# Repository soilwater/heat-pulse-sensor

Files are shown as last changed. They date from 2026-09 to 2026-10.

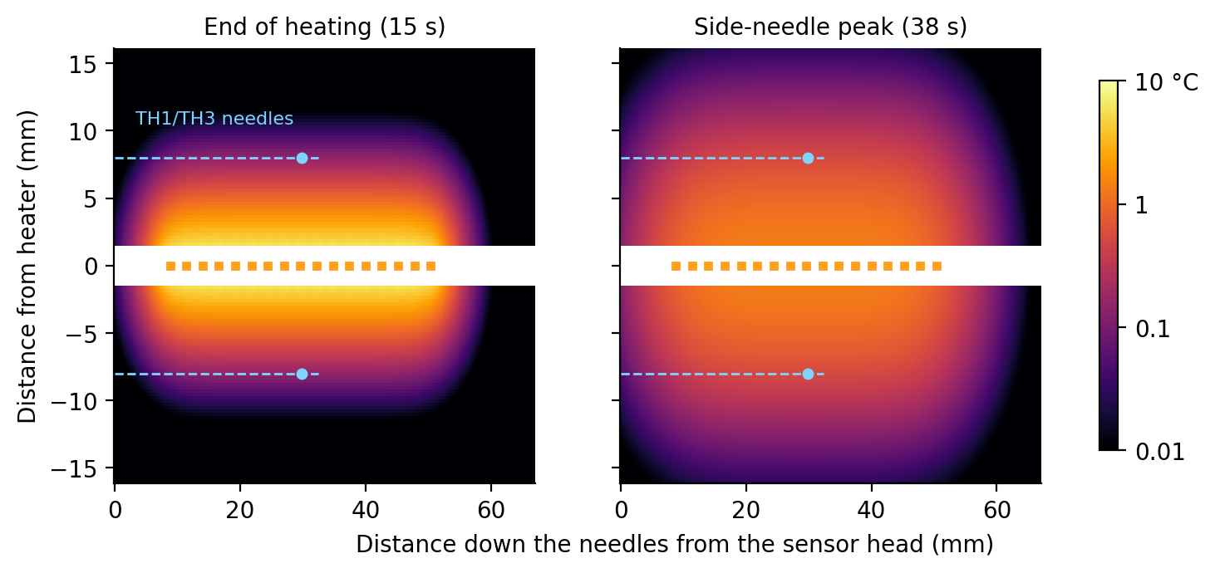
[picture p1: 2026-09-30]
docs/primer/fig/field.png

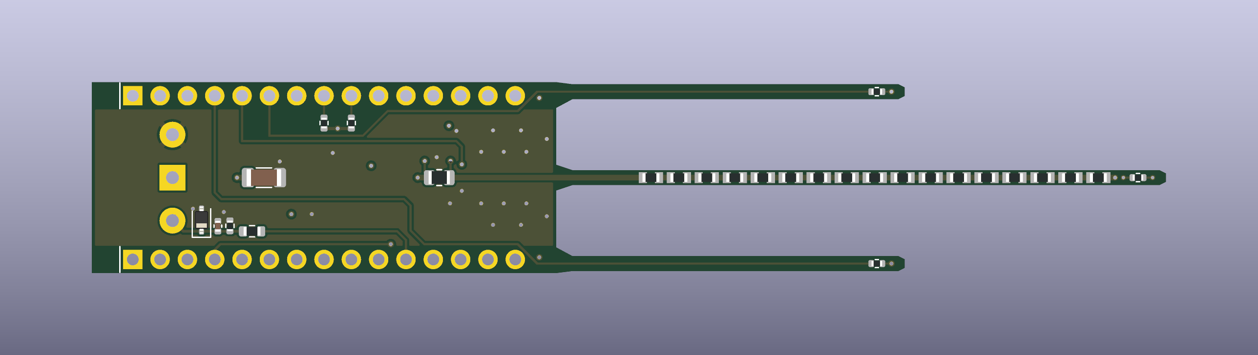
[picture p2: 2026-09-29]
hat/fab/render_top.png

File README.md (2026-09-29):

# heat-pulse

Information, datasets, and digital twins for heat-pulse sensors that measure soil thermal properties.

**Digital twin:** an interactive simulation of the HP-SDI12-NANO sensor running in real Kansas soils, published from [`docs/`](docs/). Open `docs/index.html` locally in Chrome or Edge; no installation is needed. **Guided tour** in its header steps through one measurement part by part.

## Repository layout

| Folder | Contents |
|---|---|
| [`docs/`](docs/) | The digital-twin website (static HTML, CSS and JavaScript; served as-is) |
| [`digital-twin/`](digital-twin/) | How the twin works, its data builders and tests, and the soil and heater analyses ([KANSAS_SOIL.md](digital-twin/KANSAS_SOIL.md)) |
| [`flat-nano/`](flat-nano/) | Main sensor board, HP-SDI12-NANO: KiCad sources, release checks and manufacturing files |
| [`hat/`](hat/) | Secondary design: a heat-pulse hat for the Arduino Nano R4 |
| [`reference/`](reference/) | Lab data used by the twin (Kansas Mesonet KD2 Pro workbook, logger record). Vendor manuals are kept locally, not in the repository |

## Working on the twin

```powershell
node digital-twin/sensor-model.test.js
node digital-twin/sensor-routes.test.js
node digital-twin/kansas-soil.test.js
node digital-twin/kansas-soil-build.js                          # rebuild docs/kansas-soil-data.js
& 'D:/KiCAD/bin/python.exe' 'digital-twin/export_board.py'      # rebuild docs/board-data.js from the board
```

Board release steps are in each board's README.

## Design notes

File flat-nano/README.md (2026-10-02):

# Compact flat sensor — HP-SDI12-NANO

An independent layout of the current flat heat-pulse sensor, built around the Arduino Nano R4 chip. The electronics body is **43.18 × 17.78 mm**, exactly the Arduino Nano R4 PCB outline, with every part on the top side. The WAGO connector is replaced with three plated cable solder holes. The heater is a stronger 0603 chain designed for controlled PWM heating.

## Changes after the electrical-engineering review

These changes answer an electrical-engineering review of the previous layout. The INA226 power monitor is kept; whether to keep it is still open for discussion.

- **Buck regulator instead of the linear regulator:** the HT7550-1 LDO dropped 7–9 V at the full MCU current and heated the board next to the thermistors. U3 is now a TI **LMR36503R5RPER** synchronous buck (fixed 5 V, 3–65 V input, 2.2 MHz, JLC C3190197) with a Sunlord SWPA4020S220MT 22 µH inductor (C82401), 100 nF 50 V input bypass (C307331), and a 22 µF 25 V output capacitor. Its losses are about 10 mW, on the center line.
- **Bulk input capacitor:** C3, 22 µF 25 V X5R 1206 (Samsung CL31A226KAHNNNE, JLC C12891), at the cable input.
- **Q2 removed:** D4 now powers the thermistor dividers and the ADC reference (VREF) through R11, 1.5 kΩ, which keeps the pin within the RA4M1's 4 mA output limit; the thermistors return straight to ground. Sequence unchanged: D4 HIGH, wait 10 ms, read, D4 LOW.
- **32.768 kHz crystal removed** (Y1, C5, C6): the stock Arduino core for the UNO R4 Minima / Nano R4 clocks the CPU and USB from the internal HOCO and the RTC from LOCO; it never uses the crystal.
- **USB routed as a real differential pair:** D+/D− run on the top layer only, 0.30 mm wide with a 0.20 mm gap (about 88 Ω differential on this stackup, inside USB's 90 Ω ±15 %), with no vias, over the solid inner ground plane. The SWD programming pads (J5) are removed: no external programmer is ever needed, because the chip's built-in USB boot mode (BOOT jumper on the clip) reloads the bootloader over the same clip.
- **Heater and battery current copper ≥ 0.5 mm everywhere, with no exceptions:** every trace the heater or battery current flows through, from the cable pad through the reverse-polarity diode, the shunt, the heater chain on the needle and its return, the MOSFET, and the regulator input and output, is at least 0.5 mm of 1 oz copper. The heater feed runs inside the board on the 0.5 oz In2 layer as a 1.2 mm strip, which holds more copper than a 0.5 mm outer trace, and every via on these nets has at least the barrel copper of a 0.5 mm trace. The 5 V and ground connections of the chips go through the inner planes. The three INA226 sense lines are dedicated Kelvin taps and carry no current.
- **Balanced, thermally symmetric layout:** every part that dissipates more than 2 mW (MCU, buck regulator and its inductor, input diode, 5 V OR-ing diode, shunt, heater MOSFET) sits on the board's center line. The three needles are exact mirror images, and both side-needle wires enter the body the same way. On every copper layer, the body's copper left and right of the center line must agree within 10 % (release check). This board: top 3.7 %, inner 0.9 % and 1.5 %, bottom 0.1 %.
- **Hand-planned copper, no auto-router:** every trace and via of the body is drawn deliberately by `kicad/preroute.py`. Signals run straight or at 45°. A signal changes layer only to cross the center line or another signal, and then runs at least 3 mm on the bottom layer. Every via connects copper on two layers.
- **Thermistor pin map** (same on flat-nano and the hat): A2 = TH1 right needle, A1 = TH2 heater-needle tip, A0 = TH3 left needle, A3 = TH4 board body. Left and right are as seen on the top face with the cable end up and the needles pointing down, the way the website draws the board.
- D1, D5 and D7 are Guangdong Hottech 1N5819WS 1 A 40 V Schottky diodes (SOD-323, JLC C191023, a Basic part).

**Use the complete upload set in `fab/`: `HP-SDI12-NANO_gerbers.zip`, `HP-SDI12-NANO_BOM.csv`, and `HP-SDI12-NANO_CPL.csv`. Upload all three together.**

This is the main sensor board. The `hat` folder holds the secondary Nano R4 hat design. The digital twin in `docs/` displays this board.

## Dimensions and construction

| Item | Original flat | Compact variant |
| --- | ---: | ---: |
| Electronics PCB body, excluding prongs | 60 × 18 mm | **43.18 × 17.78 mm** (Arduino Nano R4 outline) |
| Overall PCB, including prongs | 116.68 × 18 mm | **99.86 × 17.78 mm** |
| Board thickness | 0.8 mm | 0.8 mm |
| Copper layers | 2 | **4** |
| Assembly | Top side | Top side |
| Cable connection | WAGO terminal | Three plated solder holes |

The body is 16.82 mm shorter than the original flat board. All three PCB prongs are **1.4 mm wide**, providing clearance for the larger 0603 resistors within the same 12G steel needle. All prong lengths, four thermistor positions and 8 mm needle-center spacing stay unchanged. The heater uses **17 × 3.3 Ω, 1%, Vishay CRCW06033R30FKEAHP**, rated **0.33 W at 70 °C** (JLC **C313752**). Its 56.1 Ω series chain delivers about **2.34 W at 12 V** and **3.41 W at 14.4 V** under the stated cable-loss assumptions. The custom footprint follows the manufacturer's recommended reflow lands at 2.6 mm pitch. R9 is 1.5 kΩ to respect the MCU gate-drive current limit.

Use a nominal **2 W average heater-power target**, **100 Hz hardware PWM**, and **8–15 s** heating windows. At 12 V this is approximately 85% duty, with full power available when a stronger measurement is qualified. This is a firmware specification, **not implemented firmware**. See [HEATER.md](HEATER.md) for exact ratings, power calculations, synchronized current measurement, shutdown requirements and bench acceptance checks.

The 43.18 × 17.78 mm dimension describes the **bare PCB body**. The steel needles span approximately 18.77 mm across their outside surfaces, and the finished enclosure needs room for needle embedment, insulation, epoxy, and cable strain relief.

## Cable connection

J1 is a bare plated-hole feature, omitted from the factory assembly BOM and placement file. Hand-solder the three wires after assembly. There is no solder-paste aperture over these holes.

| J1 pad | Connection | Identification |
| --- | --- | --- |
| 1 | Battery +12 V | Middle pad, square, on the center line; `12V` label on underside |
| 2 | SDI-12 signal | Outer pad beside the `SDI` label on the underside |
| 3 | Ground / battery negative | Other outer pad, beside the `GND` label on the underside |

The holes have 1.2 mm nominal finished diameter, 2.4 mm copper pads, and 4 mm spacing. Use 22 AWG stranded wires with neatly tinned ends that enter freely. The nearest pad copper is 0.6 mm from the board end. Keep the cable jacket anchored in the housing or potting so cable pull does not reach the pads.

## Programming

J2 is a row of five bare holes on the long edge for an off-the-shelf 2.54 mm 5-pin pogo clip: 5V, D−, D+, GND, BOOT. Plug a "USB to 4-pin Dupont" cable onto the clip and the board is an "Arduino UNO R4 Minima" in the Arduino IDE. BOOT is used only for the very first bootloader load or for recovery: fit a jumper cap across clip pins 4–5 while plugging in. All 68 fitted components are on the top side; J1 and J2 are bare connection features.

## Files and checks

- `kicad/hp_sensor_routed.kicad_pcb`: the routed PCB.
- `kicad/hp_sensor.kicad_sch`: corresponding schematic.
- `kicad/placement.json`: component locations.
- `kicad/preroute.py`: every trace, via and pour of the body, drawn by hand plan.
- `checks/check_quality.py`: layout-quality gate for the review rules: current-path copper width, mirrored needles, left/right copper balance, heat sources on the axis, routing style (no short via-to-via jumpers, no jogs, no acute turns, no via without a purpose, no top copper under the inductor or deep under the MCU) and the USB pair.
- `kicad/export_view.py` and `kicad/plot_view.py`: layer-by-layer review drawings of the routed board.
- `preview/index.html`: dimension comparison and top/bottom assembly views.
- `fab/`: current manufacturing outputs (Gerbers, BOM, CPL, schematic PDF, renders and order settings), generated only after the release checks pass. `release.py` also writes `fab/RELEASE_MANIFEST.txt` with SHA-256 hashes of the checked board and outputs.

The release process requires zero ERC findings, zero DRC findings at all severities with zero unconnected items, schematic/PCB parity, dedicated Kelvin connections for all three current-monitor sense pins, no courtyard overlap, reserved soldering space around J1, and a pass of the layout-quality gate. A separate check keeps ordinary via holes clear of all exterior solder openings, including the cable and programming pads, to avoid solder wicking; this design does not assume filled/capped vias. This is a verified layout package; no assembled hardware has been tested.

From the project root, rebuild, check and export with:

```powershell
& 'D:/KiCAD/bin/python.exe' 'flat-nano/kicad/release.py'
```

Add `--verify-existing` to check and export the existing routed board without rebuilding it. Run with KiCad's Python environment, not a generic Python installation. This variant supports the current 12G configuration only.

## Manufacturing and assembly

Use **4-layer FR-4, 0.8 mm nominal thickness, 1 oz outer copper / 0.5 oz inner copper, green solder mask, white silkscreen, lead-free HASL finish, tented vias, and Standard PCBA on the top side only**. Select the standard **JLC04081H-7628** construction. No controlled-impedance certification is requested. The layer order is front signals, inner ground, inner +5 V (which also carries the 1.2 mm heater feed along the center line), and back signals. Both inner planes stop inside the electronics body; the needles retain their original two-sided copper construction. Unused inner via pads are removed. Keep the supplied finished-hole sizes and the needle-prong outline. Body signals are 0.2 mm wide with at least 0.127 mm clearance, and ordinary vias use 0.35 mm holes with 0.60 mm pads. Only the two heater-needle thermistor lanes use 0.09 mm traces, and the heater-needle thermistor uses two 0.30 mm-hole vias with 0.50 mm pads. The narrower paths retain the full clearance rules and fit the factory's standard multilayer capabilities.

The Gerber ZIP, BOM, and CPL must be used together from this variant's `fab/` folder. Review the supplier's component-orientation preview for this placement, in particular the polarity of D1, D5 and D7 and pin 1 of U1, U3 and U4. These local file changes do not replace files in an existing JLCPCB order; upload the three files together before production.

Any factory support tabs must be removed flush from the needle-insertion edges. Use steel needles with a measured **minimum 2.16 mm internal bore**. The heater fit calculation allows a 0.9 mm maximum PCB thickness, 1.6 mm maximum manufactured heater-prong width, 0.95 × 0.65 mm maximum resistor-plus-solder envelope and a **25 µm total radial liner including adhesive, without overlap**. Dry-fit the insulated assembly before potting; PCB thickness, routed edges, component height, and solder thickness all affect the fit. Layout checks do not replace the first assembled unit's power, programming, communication, and heating tests.

For this narrow, fork-shaped board, use **Standard PCBA with custom panel design through JLCPCB engineering and temporary supports**. The ordinary automatic Panel by JLCPCB service is not suitable for this fork-shaped outline; request the custom engineering service using the order remarks. Its minimum assembly panel is 70 × 70 mm; ordinary 5 mm rails around this 99.86 × 17.78 mm outline do not meet that width. The detailed Economic PCBA combinations do not include this four-layer, 0.8 mm construction. Request tooling holes, fiducials, and supports on the factory panel, with the sensors delivered separately and all remnants removed flush from needle-insertion edges. These supports are not part of the 43.18 × 17.78 mm finished body. Use the exact wording and settings in `fab/ORDER_SETTINGS.md`. See [assembly capabilities](https://jlcpcb.com/capabilities/pcb-assembly-capabilities) and [panel requirements](https://jlcpcb.com/capabilities/Capabilities).

The explicit stack follows [JLCPCB's published 0.8 mm JLC04081H-7628 construction](https://jlcpcb.com/impedance): 0.035 mm outer copper, 0.2104 mm 7628 prepreg, 0.0152 mm inner copper, 0.250 mm core, 0.0152 mm inner copper, 0.2104 mm 7628 prepreg, and 0.035 mm outer copper. The 0.0152 mm inner value belongs to the factory's nominal 0.5 oz option. The solder-mask model uses the published 0.01524 mm above-copper thickness on each side. Their combined model is 0.80168 mm; the specified finished thickness remains nominal 0.8 mm with the factory's published ±0.1 mm tolerance. The Gerber job records these published construction dimensions without claiming controlled impedance or a measured loss tangent.

For durable soil service, fully encapsulate the assembled electronics and cable entry using electrically insulating, low-water-absorption potting suitable for electronics. Insulate copper from the steel needles, anchor the cable mechanically, and dry-fit each assembled prong before potting. The surface finish and solder mask do not replace waterproof encapsulation.

Select **Board Cleaning: No**: the Murata NCP15 thermistors must not be cleaned after no-clean flux. Do not solvent-wash, dry-ice-clean or ultrasonically clean the assembled board. Follow the component-specific cleaning and potting guidance and the 500-character assembly remark in [ORDER_SETTINGS.md](fab/ORDER_SETTINGS.md). Evaluate the chosen potting process on a finished sensor before encapsulating the batch.

The separate solder-opening check also found ordinary via holes overlapping SMD solder openings in the original flat PCB. Those locations are corrected in this compact layout. The original board and its manufacturing files were deliberately preserved; this release does not certify their soldering geometry.

Dimension reference: [Arduino Nano R4 datasheet, mechanical drawing](https://docs.arduino.cc/resources/datasheets/ABX00142-datasheet.pdf). Manufacturing reference: [JLCPCB capabilities](https://jlcpcb.com/capabilities/Capabilities), including 0.8 mm board thickness tolerance ±0.1 mm, regular routed dimensions ±0.2 mm, and plated-hole tolerance +0.13/−0.08 mm.

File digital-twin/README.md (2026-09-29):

# Flat heat-pulse sensor dashboard

The dashboard itself lives in [`../docs/`](../docs/) and is published from there as the project website. Locally, open **`docs/index.html` in Chrome or Edge on a desktop computer**; double-clicking works without a server, installation, or internet connection. This folder holds the twin's documentation, data builders and tests. The dashboard is a single control view: the sensor drawing on the left; the temperature chart and one live **Readings** table on the right. Above them, a control row uses the same two columns: the Soil and Parts cards over the sensor, and the run controls over the chart. Soil selection and the parts list open as dialogs from those cards. The header switch changes between the dark theme (default) and the light theme; the choice is saved in this browser. It represents the current **HP-SDI12-NANO** (flat-nano) sensor with **17 series-connected 3.3 Ω resistors**, a **12 V battery**, and a **22 °C starting temperature**. It simulates a proposed measurement sequence; it does not connect to hardware or execute sensor firmware.

## Run a measurement

Three durations and one heater-duty setting are editable, and the soil is chosen with the **Soil** card above the sensor. Durations use whole seconds; duty uses whole percent:

| Setting | Range | Default |
|---|---:|---:|
| Background (sensing before heating) | 1–60 s | 10 s |
| Heating | 8–15 s | 15 s |
| Cooling (sensing after heating) | 1–600 s | 150 s |
| Heater duty | 0–100% | 85% |

## Choose a soil

Every soil is a real measurement. The **Soil** card above the sensor shows the current one (station, depth, water state, texture, λ, C, θ); it opens on a typical silty clay loam at 33 kPa, the reading closest to the Kansas 33 kPa medians. **Change** opens the **Select soil** dialog:

- Click a dot on the USDA texture triangle. There is one dot per Kansas Mesonet core; the two cores at each station depth share a position, so click again to cycle. Hover for station, depth, texture and the colored variable.
- Or narrow the list with **Texture** and pick from **Core** (grouped by station, keyboard accessible).
- **Color by** organic matter, bulk density, depth, or water content at the selected state.
- Pick a **water state** chip. Each shows that reading's water content θ. A "!" marks heat capacities flagged in the workbook's QA/QC log (all 5 and 10 kPa readings, plus individual cores); they remain selectable, and the flag text is shown.

The twin applies the choice immediately and uses that single reading's measured conductivity and heat capacity; nothing is interpolated. The dialog lists the core's texture, OM, bulk density, θ, λ and C, and plots the actual KD2 Pro reading of that sample next to the twin's prediction for the KD2 probe (30 mm, 6 mm spacing, 60 s heating), so each soil can be traced back to a real measurement. See [KANSAS_SOIL.md](KANSAS_SOIL.md) for the data, the model check against all 1,448 curves, and the expected signal range.

Press **Run measurement**, pause/resume, reset, or run again. Drag the time slider to inspect any moment. Playback speed cycles through **1×, 4×, and 10×**; this changes animation speed, not the simulated pulse duration. Changing a timing or duty value resets the measurement. Duty is the fraction of each 100 Hz PWM cycle that the heater switch is ON. At 0%, the measurement sequence still runs but the heater stays off.

Displayed time **0 starts background sensing**. The default cycle lasts **175 seconds** and contains exactly the three phases above. The underlying model's initial idle and final reporting intervals are not displayed.

The vertical sensor view uses the actual PCB outline, component positions, and copper snapshot. Scroll over the board to zoom at the pointer, or use **+ / −**; drag to pan and press **Fit** to restore the whole board. Zoom ranges from 100% to 600%. Clicking a component, a callout, or a Readings row opens its role and current values in a detail dialog; dragging does not open a dialog.

The **Parts / Top / In1 / In2 / Bot** tabs preserve zoom, pan, measurement time, and playback. Copper tabs hide component bodies and show the selected layer's actual tracks, filled copper areas, pad outlines, and drill holes. All four copper views use the same top-view coordinates; inner and bottom copper are viewed through the board, not mirrored. In1 is the ground plane. In2 is the +5 V plane and also carries the heater supply (VIN_P) as a 1.2 mm strip along the board's center line. Both inner planes stop inside the electronics body. Via annuli and pads appear only on layers where the board actually flashes copper; through-drill holes remain visible on every layer they traverse. Pad clicks and the component callouts still open details.

The drawing is a top view on a 1 mm drafting grid with a title block. Callouts give each designator and its function. The soil-temperature and circuit-activity legends float in the drawing's upper-left corner.

## Guided tour

**Guided tour** in the header walks through one measurement in 20 stops: an overview, the cable holes, surge protection and the bulk capacitor, the reverse-polarity diode, the 5 V buck regulator, the battery and USB supply diodes, the processor, the programming clip, the SDI-12 request, thermistor excitation through pin D4, how a thermistor divider measures temperature, the background reading, the heater switch, energy measurement, the heater chain, heat spreading, heater off, the side-needle peak, the board thermistor, and the result. Everything except the sensor is blurred; the camera flies to each part while its current flow is highlighted, and a card explains it at two levels: a short “In plain terms” line (the processor as the brain, a transistor as a gate, why a resistor heats up, how a thermistor senses temperature) followed by the technical account of what happens and why the part is there, with live values from the current soil. The tour also explains why the heater runs on the raw 12 V battery supply (trimmed by switching) while the processor runs on a regulated 5 V.

**Space** (or →, Enter) runs the simulation forward to the next event and stops; **←** goes back; **Esc** exits. The progress bar jumps to any stop.

The tour is two self-contained files: `tour.js`, a generic engine (spotlight, blur, card, keys, camera and time stepping) that knows nothing about heat pulses, and `tour-steps.js`, this sensor's script as plain data (parts to frame, when, plain-language line, what, why). A tour for another board needs only a new steps file and a twin exposing `seek(time)` and a camera with `focus(refs)`. The dashboard works without either file.

## Readings and the sensor estimate

The **Readings** table updates with the time slider: TH1, TH3 and TH2 temperatures and rises, the soil beside the heated section, battery draw and current, heater power and energy, and the component losses. TH4 (board) stays on the drawing but is not reported, because board heating is not modeled. Click any row for details.

**Sensor estimate** answers "what would this sensor report in this soil?". When cooling ends, the simulated TH1 record (14-bit ADC, 64 readings averaged, one sample per second) is baseline-corrected and fitted with the pulsed infinite-line-source model, as simple firmware would: from heater-on to 1.5 times the time of the measured peak (readings after that are kept but not fitted), using q′ = average heater power ÷ effective heated length (17 resistors × 2.6 mm = 44.2 mm) and the nominal 8 mm spacing. If the record ends before the peak, the estimate is flagged. The table shows the sensor's λ and C next to the soil's KD2 Pro values, with the difference. Water content is then derived from C with the de Vries relation θ = (C − ρb·0.75)/4.18 and the core's bulk density, and compared with the measured θ. The λ and C differences are the model error of the sensor and analysis, mostly from the finite heater length: about 1% or less for λ and 0.3% or less for C across Kansas soils with the default settings. The θ difference also contains the de Vries relation's own error: in the wetter states, measured C averages about 6–9% below the relation, with ±11–14% scatter.

## Parts list

The **Parts list** card opens one table of all 70 footprints (68 fitted parts plus the two hole rows), grouped by part number: designators, function, value, manufacturer, part number, LCSC number and BOM description. These are the 68 assembled components plus the J1 cable holes and the J2 programming-clip holes, which are bare hole features with no BOM rows. The BOM has no manufacturer column; manufacturers are filled in only for part-number families that identify them unambiguously, otherwise a dash. Click a designator for that part's role and live values.

J1 is drawn as three plated cable holes with incoming **12 V power, SDI-12 signal, and ground** wires from an external battery/logger. Pad 1 (+12 V) is the square middle hole on the board's center line; pad 2 (SDI-12) and pad 3 (ground) are the outer holes, 4 mm to either side. Dimension lines show **99.86 mm overall PCB length × 17.78 mm width** (43.18 mm body length, the Arduino Nano R4 outline), calculated from the exported outline and excluding the wires. All three PCB prongs are 1.4 mm wide.

Neon **yellow logic-power** and **pink signal** highlights follow the **actual exported copper tracks and vias**. Each copper tab shows activity only on its selected layer, including the **orange heater circuit**: the 0.5 mm series links between heater resistors on top, the 0.5 mm return trace (HEAT_RTN) on top and bottom, and the 1.2 mm heater-supply strip on In2. Every trace on the heater and battery-input path (cable hole, D1, R5, the heater chain and its return, Q1, and the regulator input and output) is at least 0.5 mm wide; the INA226 sense taps carry no current and are narrower, as is the 0.3 mm output-sense line to U3 pin 8 (VOUT/BIAS), which carries only U3's small bias current. In the Parts tab the orange heater path follows that copper from the middle cable hole through D1, R5 and the 17 resistors, then back along HEAT_RTN to Q1 (the shared ground-plane return is not drawn); the In2 strip is drawn there as a hatched line running under the parts. Copper pads and fills also indicate activity; shared supply and ground use yellow during sensing and orange during heating. These colors indicate circuit activity, not voltage, current density, or decoded waveforms. Supply/heater nets include sensing and protection branches, so their copper highlights pulse without claiming equal branch current or a direction everywhere. Heater traces without highlights do not necessarily have zero voltage. Component selection uses a thin unfilled rectangular border that keeps its screen width when zooming.

Before a measurement, the board uses muted copper and component colors with no automatic activity highlights. The electronics are still powered and their standby draw remains visible in the Readings table. Running or scrubbing a measurement enables highlights, including background sensing at displayed time zero. Pausing freezes them at that moment; reset clears them.

The chart and Readings table show the evolving ideal thermal response: **TH1/TH3** on the side needles and **TH2** at the heater-prong tip. Component details also show the last simulated ADC reading. The Readings table updates PWM-cycle-average battery draw, heater power, accumulated heater energy, and component/group losses. Resistor and switch dialogs also show ON current and ON power. Copper animation represents average activity; it does not flash at 100 Hz or reconstruct actual switching waveforms. **The electronics stay powered during background sensing and cooling**, even when heater power is zero.

The soil colormap uses **purple → pink → orange → yellow** and the same spatial heat equation as the temperature curves. Its fixed, logarithmically spaced **0–5 °C rise scale** keeps small side-needle responses visible without rescaling a cooling pulse; values above 5 °C saturate. The map is neutral before heating, remains warm after switch-off, and follows the same time across all copper tabs, zoom and pan. It refreshes at quarter-second simulation intervals. The physical heater-needle interior is masked rather than assigned a fictitious temperature. The map runs from the sensor head (the end of the PCB body) past the needle tips and treats everything outside the needles as uniform soil. The **References** button in the footer lists the heat-pulse theory and data sources the model uses.

**TH2 (labeled "heater tip") is 3.68 mm beyond the last heater resistor.** A separate **Soil beside heater** reading samples the ideal soil field at the middle of the heated length, 1.385 mm from the axis (the nominal 12G needle outer radius). This is a soil estimate, **not the steel, thermocouple or resistor temperature**. Click this reading or the color legend for the distinction and a comparison with the recorded experiment. The thermistor chart keeps its smaller scale so the side-needle signal remains readable.

## Heating capacity and the recorded probe

The heater chain is **17 × 3.3 Ω = 56.1 Ω** in series, using Vishay CRCW06033R30FKEAHP (LCSC C313752), 0.33 W, 1%, 0603 resistors. They are spaced 2.6 mm apart, beginning 8.8 mm from the body/prong boundary. The dashboard shows only this board and has no hardware configuration selector.

At the fixed **12 V** supply and modeled cable/circuit losses, full ON gives **204.5 mA and 2.346 W**. The default **85% duty** gives **1.994 W average and 29.91 J over 15 seconds**. Increasing duration increases energy; increasing duty increases average power. A duty of 100% delivers approximately 35.18 J in 15 seconds under these assumptions.

**The dashboard applies a fixed duty, not closed-loop power regulation.** Real firmware is intended to regulate around 2 W average at 100 Hz as battery voltage changes. For example, the model requires approximately 85.3% at 12 V but 58.6% at 14.4 V. Leaving duty at 85% on a 14.4 V supply would produce approximately 2.90 W average. That firmware has not been implemented or qualified by this dashboard.

[HEATER.md](../flat-nano/HEATER.md) records the heater part choice, electrical limits, needle fit, insulation assumptions, and bench qualification requirements. Neither the soil model nor passing PCB design rules establishes the hottest chip temperature or adequate thermal signal in a manufactured sensor.

[HEATER_CHECK.md](HEATER_CHECK.md) is the earlier analysis of `reference/probe_A25-2.dat`, the supplied construction manual, and the first 22 × 5.1 Ω heater design. Thirteen valid records show approximately 60–63 °C on the inferred heater-thermocouple channel and approximately 1.5 °C side-channel rises. The manual describes a 35–45 Ω wire heater and 14G needles. The logged heater-millivolt signal has no documented power conversion, so those records do not calibrate the current 56.1 Ω, 12G sensor. A hot needle alone does not establish the side-needle response needed for measurement.

## What the circuit model represents

- Heater current flows through **J1 pad 1 (middle hole) → D1 → VIN_P, which runs inside the board on In2 as a 1.2 mm strip → R5 → RH1–RH17 → HEAT_RTN → Q1 → ground plane → J1 pad 3**. C3 (22 µF) on VIN_P supplies the heater’s sudden current steps locally, so the long cable does not ring. Pin D9 controls Q1's gate through R9; the processor does not supply heater current. Each heater resistor releases **I_ON²R** during each ON interval. Average heat is this power multiplied by duty / 100, not the square of average current times resistance.
- **U3** is a TI LMR36503R5RPER synchronous buck regulator: fixed 5 V output, 3–65 V input, switching at up to 2.2 MHz, with L1 (22 µH), C1 (4.7 µF, 50 V input), C18 (100 nF, 50 V input bypass), C19 (100 nF bootstrap), C20 (1 µF internal supply) and C2 (22 µF output). Its loss is about 10 mW. **D7** (B5819WS Schottky) follows it onto the +5 V rail (C17, 10 µF) and keeps clip power out of the regulator; the model assumes a 0.25 V drop. The power ledger separates these losses from aggregate logic consumption. It does not invent individual processor or INA226 current consumption.
- **U4/INA226** senses R5 and HEAT_P. Its calculated power includes heater-loop copper and Q1 losses; delivered heater energy counts the 17 resistors alone. Proposed firmware must use settled ON-window single-shot shunt/bus conversions, check conversion-ready, and integrate measured ON power over actual ON time. Asynchronous PWM averages can alias and cannot simply be multiplied. The twin uses ideal ON/OFF weighted averages and does not simulate conversion timing errors.
- **R9** (1.5 kΩ, pin D9 to the Q1 gate) limits the processor's gate-charging current, and **R10** (100 kΩ) holds the gate LOW while the processor is in reset. Firmware must detach PWM and explicitly drive the heater output LOW at the deadline; stopping a timer alone is insufficient.
- Processor pin **D4** (net D4_EXC, U1 pin 45) powers VREF through **R11** (1.5 kΩ). VREF feeds the tops of the four 10 kΩ, 0.1% thermistor dividers and the ADC reference AREF (C13, 1 µF); the thermistors return straight to ground. R11 limits the pin to 5 V / 1.5 kΩ = 3.3 mA while C13 charges, within the RA4M1's 4 mA per-pin rating. With the dividers connected, VREF sits at roughly 3.5–3.7 V at 25 °C (higher when cold); readings stay ratiometric because the dividers and AREF share VREF. The dividers are unpowered between readings. The proposed sequence is pin D4 HIGH, 10 ms settling (the time constant is about 1.2 ms), 10 ms acquisition of 64 readings with `AR_EXTERNAL` and 14-bit ADC conversions, then pin D4 LOW, once every second.

Other settings are fixed in the dashboard: 5 m one-way 22 AWG cable, zero additional contact resistance at the soldered cable holes (idealized), 0.2 Ω heater-loop copper, 0.35 V D1 drop, 10 mA aggregate electronics current, 8 mm needle spacing, and uniform soil with the selected reading's λ and C. See **Model assumptions** for these limits while using the dashboard.

## Limits

The electrical model assumes constant resistance, diode drops, and electronics current. The selected Vishay CRCW06033R30FKEAHP heater is rated 0.33 W at ambient temperatures up to 70 °C, with linear derating to zero at 155 °C. Rating checks use full-ON power and resistance tolerances regardless of selected duty. Calculated power is a screening result, not qualification of the assembled needle.

Thermal curves sum finite heater point sources in homogeneous soil. They exclude steel, epoxy, PCB heat storage, contact resistance, water movement, and temperature-dependent heater resistance. **Resistor-chip temperature is not predicted. Board heating is not modeled, so TH4 is not reported.** TH1 and TH3 overlap because the modeled soil and spacing are symmetric.

ADC values include deterministic quantization and approximate settling, not validated noise, accuracy, or self-heating. The dashboard does not test SDI-12 compatibility, bootloaders, surge protection, or physical insulation. Hardware testing and calibration remain necessary.

## Source files and updates

Web app, in `docs/` (served as-is; no build step):

| File | Purpose |
|---|---|
| `index.html`, `sensor-ui.js`, `sensor.css` | Dashboard, timing and duty controls, chart, Readings table, sensor estimate, parts list, playback, and dialogs |
| `sensor-board.js`, `sensor-components.js` | Vertical PCB rendering, zoom/pan, component interactions, and explanations |
| `sensor-routes.js`, `sensor-annotations.js` | Actual copper selection, soldered cable illustration, and outline dimensions |
| `sensor-soil.js` | Select soil dialog: texture triangle, core and water-state selection, KD2 Pro curve |
| `tour.js`, `tour-steps.js`, `tour.css` | Guided tour: generic engine, this sensor's step script, and styles |
| `sensor-heatmap.js` | Fixed logarithmic soil colormap, sampled from the shared spatial temperature model |
| `sensor-model.js` | Electrical/measurement model, PWM average power ledger, ON-state values, and the sensor estimate (`soilEstimate`) |
| `engine.js` | Shared ideal-soil thermal calculations |
| `kansas-soil-data.js` | Every Kansas Mesonet core with its KD2 Pro readings, generated by `kansas-soil-build.js` from `reference/kansas_mesonet_soil_database_summary_2026.xlsx` (read by `xlsx-read.js`) |
| `board-data.js` | Exported PCB geometry, nets, BOM identities, and source hashes |

Tooling, in `digital-twin/` (not published):

| File | Purpose |
|---|---|
| `export_board.py` | Regenerates `docs/board-data.js` from the routed KiCad board and BOM, without editing KiCad sources |
| `kansas-soil-build.js`, `xlsx-read.js` | Builds `docs/kansas-soil-data.js` from the reference workbook and prints the model checks |
| `sensor-model.test.js`, `sensor-routes.test.js`, `kansas-soil.test.js`, `sensor-ui.test.cjs` | Model, routing geometry, soil-data and browser checks against the files in `docs/` |
| `KANSAS_SOIL.md`, `HEATER_CHECK.md` | Soil-data analysis and the original heater investigation |

`board-data.js` records SHA-256 hashes of `flat-nano/kicad/hp_sensor_routed.kicad_pcb` and `flat-nano/fab/HP-SDI12-NANO_BOM.csv`; the dashboard reads this snapshot rather than live KiCad data, and `sensor-routes.test.js` fails until both hashes match. After either source changes, regenerate from the repository root:

```powershell
& 'D:/KiCAD/bin/python.exe' 'digital-twin/export_board.py'
```

The compact board snapshot contains four copper layers and the saved fills, without altering the manufacturing files. J1 is three plated cable holes (no connector). The copper-loss value remains an explicit estimate, not a four-layer resistance extraction.

The exporter updates geometry, BOM metadata, and explicit heater specifications. It refuses an unexpected heater count, identity, or position. Review the model and tests separately after changes to circuit values, topology, geometry, or timing; the physics does not update automatically.

Run checks from the repository root:

```powershell
node digital-twin/sensor-model.test.js
node digital-twin/sensor-routes.test.js
node digital-twin/kansas-soil.test.js
node digital-twin/sensor-ui.test.cjs
```

`sensor-ui.test.cjs` drives the dashboard in headless Chrome: the 70 drawn parts and the current nets, copper-exact activity highlights, layer tabs, zoom and pan, playback, dialogs, the parts list, the guided-tour parts and desktop layout. It requires Playwright, which is not installed on this machine; point `PLAYWRIGHT_MODULE` at a local copy, and `CHROMIUM_EXECUTABLE` can identify an installed Chrome or Edge. These dependencies are needed only for automated tests, not for opening the dashboard.

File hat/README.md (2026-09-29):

# Compact Nano R4 heat-pulse hat

Current design: **HP-HAT**, four layers, 0.8 mm thick. The 43.18 × 17.78 mm body is exactly the Arduino Nano R4 outline and pin layout, with parts on both faces.

- [Assembly dimensions, selected headers and drawing](mechanical/ASSEMBLY.md)
- [Design, operation and manufacturing files](fab/README_HAT.md)
- [JLCPCB order settings](fab/ORDER_SETTINGS.md)
- [Release checks and file hashes](fab/RELEASE_MANIFEST.txt)

The `flat-nano` version is the reference for the needles and shared parts; its files are only read. The Nano and hat are soldered face inward with a 4.00 mm gap. The potted body target is 10.5 mm thick, which the nominal 10.49 mm stack meets only with the full 1 mm cover per face; verify the fit on the first assembly.

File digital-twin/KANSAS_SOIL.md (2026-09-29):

# Kansas Mesonet soil data in the digital twin

Source: `reference/kansas_mesonet_soil_database_summary_2026.xlsx`, a copy of the workbook in the
`kansas-soil-props` repository (SHA-256 `1c543b63…2025101`). Cite Parker, Kluitenberg, Redmond &
Patrignani (2022), *SSSAJ* 86(6):1495–1508, https://doi.org/10.1002/saj2.20465.

The workbook links 1,448 KD2 Pro SH-1 dual-needle readings to 316 of its 320 cores (40 stations, 5–50 cm,
8 water states). SH-1: 30 mm needles, 6 mm spacing, 60 readings 2 s apart, heater on for the first 60 s.
Texture coverage is silt loam, silty clay loam, silty clay, clay loam, loam and 24 sandy-loam cores:
**there are no sands**, so these data do not cover the Feb-2026 sand tests.

Rebuild and re-run the checks (≈3 s, Node only):

```powershell
node digital-twin/kansas-soil-build.js          # writes docs/kansas-soil-data.js and prints the checks
node digital-twin/kansas-soil.test.js
```

## In the dashboard

The **Select soil** dialog picks any of the 316 cores (texture triangle, texture filter or core list) and
any of its water states; the twin then runs on that single reading's measured λ and C, and the dialog shows
the reading's KD2 Pro curve beside the twin's prediction for it. The dashboard opens on the unflagged 33 kPa
reading closest to the 33 kPa medians (Hodgeman, 20 cm, silty clay loam: λ 1.28, C 2.35). After each run,
the Readings table's *Sensor estimate* shows the λ, C and θ the flat-nano sensor itself would report for that
soil (Check 2's line-source bias, computed live). See the README for how to use it.

Particle size was measured on one core of each station-depth pair (core 2) and organic matter on the
other (core 1), so both cores take texture and OM from their pair. Bulk density and all thermal readings
are each core's own.

For context, the medians per water state (printed by the build) are:

| Water state | n | λ W/(m·K) | C MJ/(m³·K) | θ m³/m³ |
|---|---:|---:|---:|---:|
| Saturated | 316 | 1.37 | 2.73 | 0.44 |
| Field capacity (33 kPa) | 312 | 1.29 | 2.33 | 0.34 |
| 70 kPa | 242 | 1.25 | 2.16 | 0.32 |
| Air-dry (2 days) | 208 | 1.05 | 1.75 | 0.17 |
| Oven-dry (40 °C) | 220 | 0.43 | 1.31 | 0.02 |

5 and 10 kPa are omitted here because the workbook's `qaqc_log` flags all of their heat capacities
(~30% low); individually flagged heat capacities are also excluded. In the panel, flagged readings stay
selectable but are marked "!" with the flag text.

## Check 1 — does the twin's heat model reproduce real curves?

Each KD2 curve was predicted from its own reported λ, C and heater power (W/m), using the same
`engine.js` functions the dashboard uses:

| Model | Peak predicted / measured (p5 · median · p95) | RMSE, median |
|---|---|---|
| Finite 30 mm heater (the twin's point-source sum) | 0.99 · **1.04** · 1.13 | 0.05 °C |
| Infinite line source | 1.01 · 1.06 · 1.15 | 0.09 °C |

The finite-length model the twin uses halves the error of the textbook line source. The remaining ~4%
overestimate is consistent with what the model leaves out (needle heat capacity, contact resistance).
When the finite model is fitted freely to the raw curves, C agrees with the KD2 value within ~2% (median),
but λ comes out ~9% higher. The instrument's λ is probably biased low, so treat KD2 λ as ±10%.

## Check 2 — what will the flat-nano sensor see in Kansas soils?

The default pulse (1.99 W average, 15 s, 8 mm spacing), run through all 1,448 measured (λ, C) pairs:

| Quantity (p5 · median · p95) | Value |
|---|---|
| Side-needle peak rise | 0.41 · **0.58** · 1.05 °C |
| Saturated soils only | 0.39 · 0.45 · 0.56 °C |
| Oven-dry soils only | 0.71 · 0.94 · 1.37 °C |
| Time of peak after heater on | 28 · 39 · 64 s |
| Soil beside heated section (needle surface) | 5.4 · 7.1 · 17.6 °C rise |
| Line-source analysis error, λ / C (finite heater only, no noise; effective length 17 × 2.6 mm, fit to 1.5 × the peak time) | λ +0.1 · +0.2 · +0.3% / C +0.0 · +0.1 · +0.1% |

Implications:

- **Wet soils give the smallest signal.** About 0.4 °C is the design case, not 0.6 °C (λ 1.5, C 2.0, the model's generic default soil).
  At 0.0063 °C per 14-bit code that is roughly 60–70 codes before noise, so noise and drift, not
  quantization, will limit C resolution. This makes the case for averaging or a longer/stronger pulse in wet soil.
- **Dry soil runs hot.** Oven-dry cores push the needle-surface soil to about +16 °C (up to +22 °C) with
  the same energy. That is a steep gradient that can drive water away from the heater in moist soil,
  and it is the hotter environment for the heater resistors.
- **Record length.** The latest peak in the Kansas data (an oven-dry core, 15 s pulse) comes 98 s after the heater
  switches on; the median is 39 s. The default 150 s cooling phase (165 s of record after heater-on) covers 1.5 × the
  peak time for every state, with margin to locate the peak. A 90 s cooling phase would end only 7 s after that latest peak.
- **Analysis error is small.** With the effective heated length (17 × 2.6 mm = 44.2 mm) and a fit from heater-on to
  1.5 × the peak time, the finite-heater error is 0.3% or less for λ and 0.1% or less for C (5th–95th percentile)
  across all Kansas states. Fitting further into the tail, where the ideal line and the finite heater agree least,
  pulls λ up.
  Needle spacing, needle heat capacity, contact and noise will dominate real-sensor errors.

## Check 3 — the engine's texture-based soil-property model (`engine.soilProps`, not used by the dashboard)

Against 1,398 measurements with texture, bulk density and water content: λ RMSE 0.20 W/(m·K) (refitting its
constants to Kansas data improved this only to ~0.18 with leave-one-station-out validation), C biased +0.12 MJ/(m³·K) overall. It
underestimates oven-dry λ by 0.18. It is not refitted because the dashboard uses measured
values directly; refit it before using it to predict properties from texture and water content.

## Limits

- KD2 Pro properties come from a 60 s heat pulse on a 30 mm, 6 mm-spaced probe. λ and C are soil
  properties and transfer to the flat-nano geometry; the KD2 *curves* do not reproduce a 15 s, 8 mm measurement.
- The readings are on small intact cores in the lab. Field contact resistance, layering and water
  redistribution around the heater are not represented.

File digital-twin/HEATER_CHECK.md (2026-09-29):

# Heater performance check — original investigation (22 × 5.1 Ω heater)

**The current flat-nano board supersedes the manufacturing decision in this original investigation.** It uses **17 × 3.3 Ω, 0.33 W Vishay heaters**, totaling 56.1 Ω. The original experimental data remain useful, but the heater calculations below describe the first 22 × 5.1 Ω PCB. See [the flat-nano heater decision and qualification](../flat-nano/HEATER.md) and [the current upload set](../flat-nano/fab/ORDER_SETTINGS.md).

The dashboard includes a duty-cycle control. At 12 V, 85% duty and 15 s, it predicts **1.994 W average**, **29.91 J** and approximately **0.607 °C side-needle rise** under the stated ideal-soil assumptions. At 100% duty the same pulse gives **2.346 W**, **35.18 J** and **0.714 °C**; at 14.4 V / 100% it gives **3.412 W**, **51.18 J** and **1.039 °C**. These remain model predictions, not measured PCB performance. On the current board TH2 is 3.68 mm beyond the last heater center; it does not measure the hottest resistor.

The field-control specification targets approximately **2 W average using measured power**, so it would reduce duty as the battery charges. The dashboard's direct duty control instead lets you inspect a fixed 12 V example. Neither the dashboard nor this specification constitutes implemented sensor firmware.

---

Initial review, 23 September 2026. This note addresses the concern that the hardware must be able to **“deliver a punch if necessary.”** The recorded measurements confirm a hot heater needle in the older wire-heater probe. The first 22 × 5.1 Ω PCB had less heater power, and the digital twin cannot certify its assembled thermal performance. At the time of this initial check, no manufacturing files or component selections had been changed.

## What the recorded experiment shows

Source: [probe_A25-2.dat](../reference/probe_A25-2.dat). Its TOA5 header identifies a CR1000 and the program `One Thermo-TDR Probe Calibration Andreas All TCs.CR1`; that program source is absent. The table has 4,200 readings: fourteen 300-second records at one-second intervals, starting every two hours. `Htr_mV` is nonzero at counters 8–22 inclusive: fifteen heated samples per record.

For each record, baseline is the arithmetic mean of counters 0–7; peak is the largest subsequent channel value; rise is peak minus baseline. The first record contains impossible T2 values and T3 startup faults, so its T2/T3 results are excluded. No filtering was applied to the thirteen subsequent records. T2's units field is blank; its stable baseline, pulse response and comparison with the construction manual strongly indicate the heater thermocouple, but the missing logger program prevents definitive channel-map verification.

| Channel, thirteen valid records | Median baseline | Median peak | Median rise | Rise range | Median peak after switch-on |
| --- | ---: | ---: | ---: | ---: | ---: |
| T1 | 17.958 °C | 19.436 °C | 1.477 °C | 1.465–1.512 °C | 85 s |
| T2, inferred heater thermocouple | 17.969 °C | 60.211 °C | 42.241 °C | 42.215–44.743 °C | 14 s |
| T3 | 17.969 °C | 19.486 °C | 1.517 °C | 1.440–1.542 °C | 83 s |

T2 peaks at **60.163–63.208 °C**, always on the last heated sample. These data support the reported 50–60 °C heater temperatures. The median standard deviation of the eight baseline samples is approximately 0.0026 °C for T1/T3 and 0.0020 °C for T2; those short-record statistics characterize this older setup, not the PCB's thermistors or ADC.

| Record start | T1 rise | T2 baseline → peak | T3 rise |
| --- | ---: | ---: | ---: |
| 2025-03-18 10:00 | 1.408 °C | invalid startup | invalid startup |
| 2025-03-18 12:00 | 1.479 °C | 18.085 → 60.480 °C | 1.514 °C |
| 2025-03-18 14:00 | 1.481 °C | 17.995 → 60.290 °C | 1.515 °C |
| 2025-03-18 16:00 | 1.476 °C | 18.005 → 60.220 °C | 1.520 °C |
| 2025-03-18 18:00 | 1.477 °C | 17.946 → 60.211 °C | 1.518 °C |
| 2025-03-18 20:00 | 1.478 °C | 17.965 → 60.203 °C | 1.521 °C |
| 2025-03-18 22:00 | 1.512 °C | 17.990 → 60.226 °C | 1.542 °C |
| 2025-03-19 00:00 | 1.476 °C | 17.944 → 60.180 °C | 1.517 °C |
| 2025-03-19 02:00 | 1.466 °C | 17.922 → 60.163 °C | 1.516 °C |
| 2025-03-19 04:00 | 1.476 °C | 17.961 → 60.203 °C | 1.513 °C |
| 2025-03-19 06:00 | 1.477 °C | 17.981 → 60.235 °C | 1.518 °C |
| 2025-03-19 08:00 | 1.465 °C | 17.969 → 60.202 °C | 1.504 °C |
| 2025-03-19 10:00 | 1.484 °C | 17.925 → 60.163 °C | 1.527 °C |
| 2025-03-19 12:00 | 1.495 °C | 18.465 → 63.208 °C | 1.440 °C |

## Why the older probe is a different heater

The supplied [Thermo-TDR Construction Manual](<../reference/Thermo-TDR Construction Manual.pdf>) (kept locally; not in the repository) provides these primary construction details:

- **Page 4:** the center needle contains both the heater and a thermocouple. All three thermocouple junctions lie at the same axial position, within the heated section; adjacent needles are 8 mm apart.
- **Page 7:** 38 AWG heater wire is folded three times over a 42 mm guide. A handwritten note specifies approximately 35–40 Ω.
- **Page 24:** the printed heater acceptance range is **35–45 Ω**.
- **Page 25:** the heater wire is Nichrome 80, 40.63 Ω/ft; the needles are **14 gauge stainless steel**, filled with thermally conductive Omegabond 101 epoxy.

With an ideal **12 V actually across 35–45 Ω**, this construction would dissipate **3.20–4.11 W**. That is a conditional circuit calculation, not measured power from the log. `Htr_mV` averages approximately 296–302 mV during heating, but the shunt value and conversion to current are undocumented. The log therefore does not establish exact amperes, watts or pulse energy. The previous 37 Ω / 0.30 A estimate is consistent with the construction range but is not a measured calibration recovered from this file.

The first 22 × 5.1 Ω PCB had a **112.2 Ω** heater (22 × 5.1 Ω), a 43 mm heated length, **12 gauge needles**, epoxy and an FR-4 prong. Different steel, epoxy and PCB heat storage prevent direct transfer of the older probe's calibration.

## What the first 22 × 5.1 Ω PCB and original model provided

The following calculations use the twin's circuit-loss assumptions: 5 m one-way 22 AWG cable, 0.35 V input-diode drop, 0.1 Ω shunt, 0.032 Ω MOSFET, 0.2 Ω heater-loop copper and 10 mA electronics load. Side-temperature predictions assume homogeneous soil with conductivity **1.5 W/(m·K)**, heat capacity **2 MJ/(m³·K)** and **8 mm spacing**.

| Battery / pulse | Heater power | Heater energy | Energy per heated length | Predicted side-needle rise |
| --- | ---: | ---: | ---: | ---: |
| 12 V / 8 s | 1.190 W | 9.52 J | 221 J/m | 0.197 °C |
| 12 V / 12 s | 1.190 W | 14.28 J | 332 J/m | 0.293 °C |
| 12 V / 15 s | 1.190 W | 17.85 J | 415 J/m | 0.364 °C |
| 14.4 V / 15 s | 1.731 W | 25.97 J | 604 J/m | 0.529 °C |

Changing 8 s to 15 s increases energy by **87.5%** without increasing instantaneous resistor power. A battery at 14.4 V provides about **45% more power** than at 12 V under these assumptions. Neither change makes the 22 × 5.1 Ω heater equivalent to the older 35–45 Ω wire heater. Treat 14.4 V as a normal charging condition, not a requirement to boost the battery. Do not overdrive that chain's 0.1 W resistors to chase a needle temperature.

The twin's **TH2 is at the heater-prong tip**, at axial position 54.08 mm; the last center of the 22 × 5.1 Ω chain was at 50.8 mm (on the current board, RH17's center is at 50.40 mm, 3.68 mm short of TH2). The older thermocouple lies inside the heated section. Even within the same ideal model, a 12 V / 15 s pulse from the 22 × 5.1 Ω chain gives about **0.64 °C rise at TH2's location** versus **4.85 °C at the heated midpoint**, using the model's 0.85 mm effective radius. Neither number predicts the temperature of a resistor chip or the actual steel needle. Steel conduction, epoxy/contact resistance, FR-4 heat storage and water movement are absent from the model.

## Acceptance decision and a stronger candidate

Use **15 s as the initial intended pulse** when testing the 22 × 5.1 Ω hardware; [HEATER.md](../flat-nano/HEATER.md) gives the qualification plan for the current board. For this project, adopt a provisional engineering acceptance target of **at least 0.5 °C rise on each side needle and at least ten times its measured baseline RMS noise**, in representative wet and dry media at the lowest intended battery voltage. This is a chosen practical margin, not a universal heat-pulse physics threshold. Also verify repeatability, recorded heater energy and recovery of known reference-medium properties. A hot center needle alone does not establish adequate signal at the sensing needles.

The 22 × 5.1 Ω chain's 12 V / 15 s model result (0.364 °C) is **below that chosen 0.5 °C target**. Physical tests may differ, but the evidence could not certify that hardware against this target or promise the older probe's response.

The initial 0402 candidate, subsequently superseded by the stocked 0603 Vishay selection, was **22 × Panasonic ERJPA2J2R7X, 2.7 Ω, ±5%, 0402**, giving 59.4 Ω total. Its ERJPA2 series specifies **0.20 W at 70 °C ambient**, with a separate 0.25 W terminal-temperature rating. Use the conservative 0.20 W screening figure while evaluating actual terminal temperatures and derating; these ratings are not interchangeable. See the [Panasonic ERJP/ERJPA datasheet, ratings and derating on pages 2–3](https://industrial.panasonic.com/cdbs/www-data/pdf/RDO0000/AOA0000C331.pdf).

With the same circuit-loss assumptions, this candidate gives approximately **2.22 W at 12 V** and **3.23 W at 14.4 V**, or **33.3–48.4 J for 15 s**. The one-high/21-low ±5% resistance corner gives approximately **0.116 W / 0.169 W** in the hottest resistor at those two supplies. These are screening calculations. Exact sourcing and factory assembly, component/package compatibility, switch/protection margins, thermal behavior and pulse safeguards still require qualification. This was a candidate calculation only. The current board uses the 17-part Vishay design identified at the top of this note.

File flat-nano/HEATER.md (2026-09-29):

# Flat-nano heater decision and qualification

Engineering review: 23 September 2026. This heater has more power than the original flat board's, while retaining the Nano-size electronics body and the existing needle lengths and sensing positions. The selected parts and circuit calculations support the design; they do not constitute physical validation of a manufactured, insulated and potted sensor.

## Selected components

| Function | Exact part | JLCPCB part | Quantity per board | Public stock checked |
| --- | --- | --- | ---: | ---: |
| Heater | Vishay **CRCW06033R30FKEAHP**, 3.3 Ω, ±1%, 0603, **0.33 W at 70 °C ambient** | [C313752](https://jlcpcb.com/partdetail/VishayIntertech-CRCW06033R30FKEAHP/C313752) | 17 | 1,534 |
| R9 gate resistor | UNI-ROYAL **0402WGF1501TCE**, 1.5 kΩ, ±1%, 0402, 62.5 mW | [C25867](https://jlcpcb.com/partdetail/26610-0402WGF1501TCE/C25867) | 1 | 2,202,352 |

Stock was returned by JLCPCB's public component search at **2026-09-23 22:03 UTC**, not reserved. Heater prices were $0.1097 each for 1–49 pieces, $0.089 for 50–149, and $0.0788 for 150–499; the 17 fitted heaters therefore cost approximately $1.87 per board at the smallest tier before assembly, attrition and other charges. Gate resistors were $0.0029 each at 1–999. JLCPCB reported heater minimum placement quantity 5 and attrition quantity 2; its final quotation determines the charged quantity.

The heater chain is **17 × 3.3 Ω = 56.1 Ω nominal**, with centers spaced 2.6 mm. Nominal cold resistance is 55.539–56.661 Ω before wiring, copper and switch resistance. This is a different calibration from the previous 22 × 5.1 Ω chain; update firmware configuration, heater validation limits and thermal geometry together. An aggregate resistance measurement cannot identify every individual resistor defect.

The [Vishay primary datasheet, revision 17 March 2026](https://www.vishay.com/doc?20043=), specifies the 0.33 W ambient rating, temperature derating, lead-free-compatible pure-tin terminations and reflow assembly. Its separate terminal-temperature rating is not used to inflate the conservative rating here. Page 9 gives a maximum body envelope of 1.70 × 0.95 × 0.55 mm. Recommended reflow lands are 0.75 mm long × 1.00 mm wide each, 0.75 mm apart internally, for 2.25 mm total length. At 2.6 mm pitch, adjacent pads have a nominal 0.35 mm gap before solder-mask expansion. Film temperature must remain within the manufacturer's limit; the assembled potting process also requires qualification.

## Available power and the PWM operating requirement

The table assumes 5 m one-way 22 AWG cable (0.53 Ω loop), a 0.35 V input diode drop, 0.1 Ω shunt, 0.032 Ω MOSFET, 0.2 Ω heater-loop copper, and 10 mA electronics load. These are design estimates, not measurements.

| Battery voltage | Full-ON current | Full-ON heater power | Full-ON energy, 8 / 15 s | Duty for 2.0 W average |
| --- | ---: | ---: | ---: | ---: |
| 11.5 V | 0.196 A | 2.147 W | 17.18 / 32.21 J | 93.1% |
| 12.0 V | 0.204 A | 2.344 W | 18.76 / 35.17 J | 85.3% |
| 14.4 V | 0.247 A | 3.410 W | 27.28 / 51.16 J | 58.6% |

The intended default is **2.0 W average heater power, 100 Hz PWM, 8–15 seconds**. This gives **16–30 J** independent of battery voltage while sufficient electrical headroom remains. Closed-loop control must use measured power; the percentages above are explanatory starting estimates. Longer or thinner cables, a low battery, or higher actual circuit losses can prevent 2 W. Saturate at 100% duty, report achieved power/energy, and flag an unmet target rather than extending the authorized pulse silently.

**These are firmware requirements, not a claim that PWM regulation has been implemented or tested.** Every configuration must retain a hard maximum heating duration of 15 s and an explicit OFF state on reset, faults and measurement completion. Detach/disable the PWM output and then drive its GPIO LOW: stopping a timer alone must not leave the output HIGH. Full-ON operation is available for qualified experiments; the normal target remains 2 W. Do not raise the battery voltage above the intended charging range to obtain more power.

PWM reduces average power but does not reduce the instantaneous power during ON intervals. For one resistor at +1% and the other sixteen at −1%, the hottest resistor dissipates approximately **0.142 W at 12 V** and **0.206 W at 14.4 V**, using the losses above. Ignoring all circuit losses gives conservative supply-voltage bounds of **0.155 W** and **0.224 W** respectively. The latter is approximately 68% of the 0.33 W rating at or below 70 °C. Apply temperature derating; at 100 °C the conservative ambient rating is approximately 0.214 W, below that zero-loss bound. Resistance temperature coefficients and measurement errors require additional margin.

Use **90 °C as a provisional maximum measured hottest-resistor temperature during qualification**, leaving margin below the conservative ambient derating intersection. This is a chosen operating limit, not a temperature that current hardware can guarantee or directly monitor. **TH2 is near the prong tip and is not a measurement of the hottest resistor.** Assess the hottest region with an independent temperature measurement during bench qualification.

## Gate drive and measured energy

R9 changes from 1 kΩ to **1.5 kΩ ±1%** (R12 was removed together with Q2). The [Renesas RA4M1 datasheet, table 2.6](https://www.renesas.com/en/document/dst/ra4m1-group-datasheet), limits the relevant GPIO source-current group to 4 mA. At 5.5 V, 1.485 kΩ limits the initial ideal gate-charge current to approximately 3.70 mA. The gate pulldown R10 remains essential. A 100 Hz carrier allows slow, low-loss switching without using a high switching frequency merely for appearance.

The [TI INA226 datasheet](https://www.ti.com/lit/ds/symlink/ina226.pdf) describes sequential shunt and bus conversions. Unsynchronized PWM sampling can alias; multiplying independently averaged current and voltage does not generally give the correct heater energy. The implementation requirement is a settled ON window with single-shot shunt-plus-bus conversion, **588 µs configured per conversion, averaging 1**, allowing the specified conversion maximum of approximately 646 µs per channel and polling conversion-ready. Check that both conversions finish inside the same ON interval. Average valid cycles in software and integrate measured ON power over actual ON time. At very small requested duty, the measurement method must explicitly preserve a sufficiently long ON window or use another validated acquisition scheme.

INA226 bus voltage is sensed at HEAT_P. Its voltage-times-current result includes downstream copper and MOSFET dissipation as well as the heater resistors. Subtract characterized downstream losses when reporting resistor-only energy, or clearly identify the result as delivered heater-loop energy. Validate the complete method against an independent current/voltage measurement; the twin's ideal duty-weighted result does not validate conversion timing.

## Needle fit and insulation

All three PCB prongs are narrowed to **1.40 mm nominal**; their lengths, spacing and thermistor positions stay unchanged. The mechanical acceptance envelope is **actual width no greater than 1.60 mm**, **PCB thickness no greater than 0.90 mm**, and a resistor envelope **0.95 mm wide × 0.65 mm above the PCB**. The last figure includes the manufacturer's 0.55 mm maximum body height plus a **0.10 mm engineering allowance for solder standoff**, which must be verified on assembled boards. The Murata thermistors also have a 0.55 mm maximum height, so the same solder-height allowance is used for their fit checks. The heater needle's two bottom thermistor lanes run at ±0.455 mm beside the 0.5 mm heater return and use 0.09 mm traces, 0.16 mm from the return trace and 0.135 mm from the return via's pad (the release DRC minimum is 0.127 mm). The tip thermistor's two vias use 0.50 mm pads with 0.30 mm holes; the heater-return via is 0.55/0.35 mm, so its barrel holds at least the copper of a 0.5 mm trace. Body signal traces are 0.2 mm, and other vias are 0.60/0.35 mm. The [factory's standard multilayer capabilities](https://jlcpcb.com/capabilities/Capabilities) accommodate these sizes without an ENIG or filled-via requirement.

Require an **actual minimum unobstructed bore of 2.16 mm** over the insertion region; a nominal gauge or catalog ID alone does not establish that minimum. Checking all four PCB corners and all four component corners together, the maximum bare cross-section above has a minimum enclosing diameter of approximately **2.051 mm**. A uniform **25 µm radial** internal dielectric liner reduces diameter by 50 µm, leaving a **2.110 mm usable bore** and approximately **0.059 mm diametral clearance**. The 0.65 mm component height excludes this liner; the liner is counted once through the bore reduction. The heater and TH2 share one tube-axis position along the rigid prong. The side needles have about 0.118 mm diametral clearance with their narrower thermistor envelope. A conservative ±0.10 mm lateral heater-placement allowance reduces heater-needle diametral clearance to approximately 0.016 mm. This supports the design envelope but does not guarantee a slip fit through an irregular real needle. A thicker adhesive layer, seam overlap, solder protrusion, burr or local bore restriction can invalidate it.

If a liner is used, **25 µm means its total installed thickness including adhesive**, with no overlap in the insertion section. Ordinary tape specified as 25 µm film plus adhesive does not meet that envelope automatically. Dry-fit and inspect the actual assembled, insulated prong in the actual needle before potting; never force it or scrape its insulation. Reject or rework combinations that bind, and check electrical isolation from steel before and after potting. A measured larger bore or smaller actual prong provides useful margin. The dimension calculation does not certify coating uniformity, long-term insulation or moisture resistance.

## Physical qualification before field deployment

Test complete assemblies in representative **wet and dry intended media**, at the lowest intended battery voltage and at 14.4 V. Measure current, ON timing, integrated energy, actual hottest-resistor temperature, side-needle response and recovery. Repeat pulses to assess drift and repeatability, and check resistance and steel isolation after curing and environmental exposure.

For this project, use a provisional acceptance target of **at least 0.5 °C rise on each side sensing needle and at least ten times its measured baseline RMS noise**. These are chosen engineering margins, not a universal standard. Also confirm that measurements recover known reference-medium properties with the required accuracy. A hot heater needle by itself is insufficient evidence. Layout/ERC/DRC and the digital twin can support these checks; none can promise a successful first physical sensor or replace the assembled thermal and insulation tests.

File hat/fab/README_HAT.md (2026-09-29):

# HP-HAT — compact heat-pulse sensor for Arduino Nano R4

The hat applies the same review rules as flat-nano, at the exact Arduino Nano R4 footprint:

- **Nano outline and pins.** The body is exactly the Nano R4 PCB outline, **43.18 × 17.78 mm**, with the Nano's two pin rows at their exact positions. To fit, parts sit on **both faces**. The top face, toward the Nano, carries low parts inside the 4 mm gap. The bottom face, outward, carries the power stage, INA226 and thermistor dividers, which the potting covers.
- **Power copper.** Every trace carrying heater, battery or Nano-supply current is at least 0.5 mm on the outer layers, with no narrower neck. The heater supply (VIN_P) and the Nano supply (NANO_VIN) run inside the board as 1.2 mm strips on the 0.5 oz In2 layer, which is more copper than 0.5 mm of 1 oz outer copper. Every via on those nets has a barrel at least equal to that trace. The cable ground hole and both Nano ground pins connect to the pours through 0.5 mm spokes.
- **Heat on the axis.** Every part dissipating more than 2 mW sits on the center line: D1, R18, R5 and Q1.
- **Balanced left and right.** The three needles are exact mirror images, and both side-needle wires enter the body the same way. On every copper layer, the body's copper left and right of the center line must agree within 10 % (release check). This board: top 7.2 %, inner 0.5 % and 3.2 %, bottom 6.7 %. To help the top side balance, the right-needle (TH1) and tip (TH2) thermistor wires run north of the center line and the left-needle (TH3) wire south of it.
- **Hand-planned copper.** Every trace and via of the body is placed by `kicad/preroute.py`, and `kicad/gen_pcb.py` draws the needle copper, identical to flat-nano; no auto-router. Signals run straight or at 45°, and a via appears only where a signal changes layer.

Carried over from the previous hat circuit: bulk input capacitor C3 (22 µF 25 V 1206), no Q2 thermistor switch (D4 drives the dividers and AREF through R11, now 1.5 kΩ so the pin stays within the RA4M1's 4 mA output limit), and the SMF15CA input TVS.

Needles, needle copper and the heater and needle thermistors are identical to flat-nano; both bodies are the 43.18 × 17.78 mm Nano outline. The complete bare PCB outline is **99.86 × 17.78 mm**. It uses **four copper layers, 0.8 mm nominal thickness and lead-free HASL**. The flat-nano files are only read, never changed.

Use a **headerless Arduino Nano R4, ABX00142**, with its components facing the hat's top face across a **4.00 mm gap**. Two **Samtec HTSW-115-07-T-S** strips are soldered to both boards, making a permanent compact stack. The field cable is soldered into J1's three holes from the hat's outer face. Ordinary loose pins held by epoxy are not reliable electrical contacts.

The parts on the hat's outer face add up to 1.55 mm there. That puts the nominal potted stack at **10.49 mm with 1 mm of epoxy over each face**, so the 10.5 mm body target is met only nominally. Before committing a mold, check the first assembly and choose between a thinner cover over the hat's outer face and a thicker mold. See the [assembly guide and drawing](../mechanical/ASSEMBLY.md) for dimensions, part sources, wire routing and tolerances.

## Manufacturing files

Use these three files together:

| File | JLCPCB upload |
| --- | --- |
| `HP-HAT_gerbers.zip` | PCB Gerbers (includes top and bottom paste) |
| `HP-HAT_BOM.csv` | Assembly BOM |
| `HP-HAT_CPL.csv` | Assembly placement, top and bottom |

[ORDER_SETTINGS.md](ORDER_SETTINGS.md) contains the factory selections and a remark below 500 characters. The PCB has **49 factory-fitted components**:

- **28 on the top face:** the 17 heater resistors, the three needle thermistors, shunt R5, bulk capacitor C3, the SDI-12 protection (R3, R4, C4, D4) and the I2C pull-ups R6 and R7.
- **21 on the bottom face:** D1, D2, C1, C17, R18, Q1, R9, R10, U4, C12, R11, C13, TH4 and the divider bank R21–R24 and C21–C24.

J1, J3 and J4 are deliberately excluded from the assembly BOM/CPL; fit the wires, headers and Nano after delivery. Purchase the Nano and two HTSW strips separately; they are not supplied by this JLCPCB package.

The editable board is `../kicad/hp_hat_routed.kicad_pcb`. Its matching schematic is `../kicad/hp_hat.kicad_sch`. Changes belong in the generators, `placement.json` and `preroute.py`, so that rebuilding preserves the design. Run `D:\KiCAD\bin\python.exe hat/kicad/release.py` from the project folder to regenerate, check and export. `--verify-existing` checks and exports the existing routed board without rebuilding it.

## Operation and shared components

Use the intended clean **12 V battery/logger supply, normally 11.5–14.4 V**, with **8–15 s heater pulses**. RH1–RH17 are the same heater as flat-nano: Vishay **CRCW06033R30FKEAHP**, 17 × 3.3 ohm 0603 in series, nominally 56.1 ohm, 0.33 W each at 70 °C. Full-on at 12 V is roughly 2.3–2.5 W; the intended default is 2 W average via 100 Hz PWM with a hard 15 s limit. See `flat-nano/HEATER.md` for the power, derating and needle-fit calculations. Use INA226 measurements to calculate delivered energy. Resistor tolerance, temperature, potting and pulse repetition still matter; these calculations are not a completed thermal qualification.

D2 retains the hat's SMF15CA, the intentional exception to the flat-nano shared BOM, for the Nano supply branch. The Nano's regulator supplies the 5 V circuits. R18 is a filter resistor, not an overvoltage regulator; D2 does not guarantee protection against every surge above the Nano's allowed input. This is the battery/logger configuration, not a lightning-qualified input. USB alone can power logic but cannot power the battery-fed heater.

| Nano pin | Function |
| --- | --- |
| D2 | SDI-12 data |
| D4 | Powers the thermistor dividers and AREF through R11; HIGH enables |
| D9 | Heater gate, HIGH enables |
| A0 / A1 / A2 | Left / heater-tip / right thermistors (TH3 / TH2 / TH1), the same map as flat-nano. Left and right are as seen on the top face (toward the Nano) with the cable end up and the needles pointing down; from the outer face they appear swapped. |
| A3 | Body thermistor TH4 |
| A4 / A5 | INA226 I2C SDA / SCL, address 0x40 |
| AREF (B0 on pinout) | Thermistor reference, driven from D4 through R11 |
| 5V | Supplies the INA226 and the I2C pull-ups |
| VIN | From the protected battery supply through R18 (22 ohm) |
| GND | J3.12 (digital row) and J4.14 (analog row) |
| BOOT (B1) | Unconnected on the hat |

The connector rows are checked for the face-inward orientation: J3 digital row at +7.62 mm, J4 analog/power row at −7.62 mm. USB faces the cable end. This design is specifically for the Nano R4; a classic Nano, Nano Every or a reversed Nano is not the intended assembly.

## Checks and first assembly

The release procedure checks schematic/PCB parity, ERC, and DRC at all severities. It also checks all three Kelvin sense connections and via-hole separation from solder openings on both faces. The layout quality gate covers power copper, mirrored needles, left/right copper balance, heat sources on the axis and routing style. The remaining checks cover component courtyards on both faces, all four copper layers and the inner-plane assignments. They confirm the exact Nano outline, the needles against flat-nano, and BOM/CPL/Gerber consistency for both assembly sides. The procedure separately verifies 30 Nano contact positions/nets and conservative envelopes for the parts facing the Nano. The smallest separation after the documented allowances is **0.495 mm**, against a 0.40 mm minimum.

These are CAD/manufacturing checks, not proof of a functioning potted sensor. Before potting the first unit:

1. Assemble and measure the 4.00 mm gap and finished height, including the hat's outer-face parts and wire terminations. Check needle fit with the actual tubing and electrical insulation.
2. Upload firmware through the Nano's USB-C port. The repo contains hardware instructions, not a validated hat firmware release. Firmware must select the external ADC reference and 14-bit readings, control excitation settling, force heating off on timeout/fault, and enforce the maximum 15 s pulse and input-voltage limit. Do not heat above 15 V input; normal operation is the battery range stated above.
3. Verify all four temperature readings, heater voltage/current and energy, heater-off behavior and communication with the actual logger/cable. The direct SDI-12 GPIO receive threshold is not guaranteed for every compliant sender; verify the intended Campbell setup.
4. Recheck readings after a trial potting cure. The Nano has its own regulator and LEDs, so its standby consumption differs from the flat sensor; measure it and use logger-switched power where practical.

Do not wash the whole assembly: the selected Murata thermistors require the specified no-clean process. Pot only tested assemblies using compatible materials. USB access is for programming before final encapsulation; this version has no exposed waterproof USB connector.

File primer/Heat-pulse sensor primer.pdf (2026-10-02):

HP-SDI12-NANO heat-pulse sensor · background chapter · September 2026

# How the heat-pulse sensor works

An introductory chapter on the electronics and the heat-transfer model behind the digital twin, written for a first-year electrical-engineering student and for anyone coming from agronomy or soil science.

Andres Patrignani, Garrett Peterson, Gerard Kluitenberg, Eduardo Santos, and Bala Natarajan

AI disclosure. This chapter was drafted with Claude Opus 5.5 (Anthropic), an AI assistant, in September 2026. Working from the authors’ instructions, peer-reviewed articles provided by the authors, team meeting notes, correspondence between team members, the sensor design files, the digital twin, and its own general knowledge, it wrote the text, wrote the Python code that draws the figures, and ran the calculations. Most calculations were also implemented in a Jupyter notebook for reproducibility and scrutiny by the authors. The authors directed the work, reviewed and edited the content, and are responsible for it.

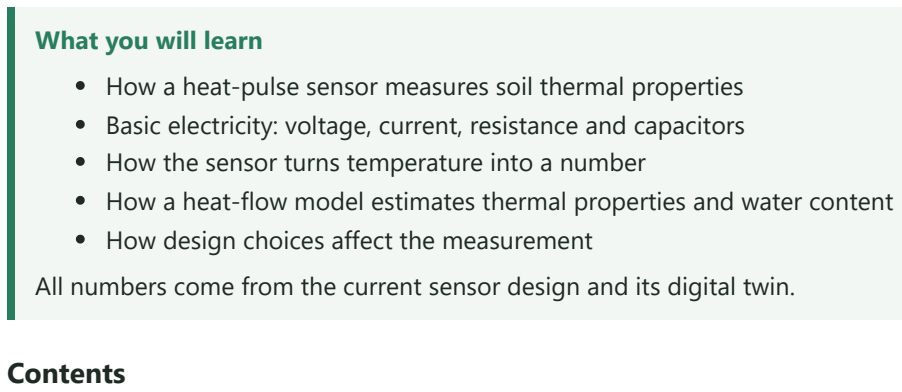
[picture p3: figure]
What you will learn; Contents

How a heat-pulse sensor measures soil thermal properties
Basic electricity: voltage, current, resistance and capacitors
How the sensor turns temperature into a number
How a heat-flow model estimates thermal properties and water content How design choices affect the measurement
All numbers come from the current sensor design and its digital twin.
1. The measurement in one page
2. Electricity for soil scientists
2.1 Voltage, current, resistance
2.2 Ohm's law and power, with the heater 2.3 Series resistors and the voltage divider 2.4 Capacitors and the RC time constant
3. The thermistor circuit, part by part
3.1 The thermistor
3.2 Why a reference resistor
3.3 From voltage to a number: the ADC
3.4 Why the thermistors are switched on only to read 3.5 Why R11
3.6 Why C13 and C21–C24
3.7 One reading, millisecond by millisecond
3.8 Where the parts sit on the board
4. Heat in soil
5. The line-source model
5.1 The heat equation
5.2 Assumptions and boundary conditions 5.3 Continuous and pulsed line source

5.4 Reading soil properties from the peak 5.5 Worked example
5.6 From heat capacity to water content
6. The digital twin's model
6.1 Seventeen point sources
6.2 "Grid" resolution and time steps
6.3 Why the estimate differs from the soil 6.4 A real KD2 Pro curve
7. What if...? Design choices, one at a time 7.1 How to read this section
7.2 Two rules of thumb
7.3 Needle spacing
7.4 Heating time
7.5 Longer needles
7.6 How much of the curve to fit 7.7 All cases in two tables
7.8 Choosing settings
8. The whole chain in one table
9. Glossary
10. References
Appendix A. Parts list

## 1. The measurement in one page

The sensor has a small circuit board (the "head") and three thin needles that go into the soil. The center needle is a heater: seventeen tiny 3.3 Ω resistors in a row. The two side needles carry thermometers (thermistors TH1 and TH3), 8 mm away from the heater. A third thermistor, TH2, sits at the tip of the heater needle, and TH4 sits on the board to report the board's own temperature.

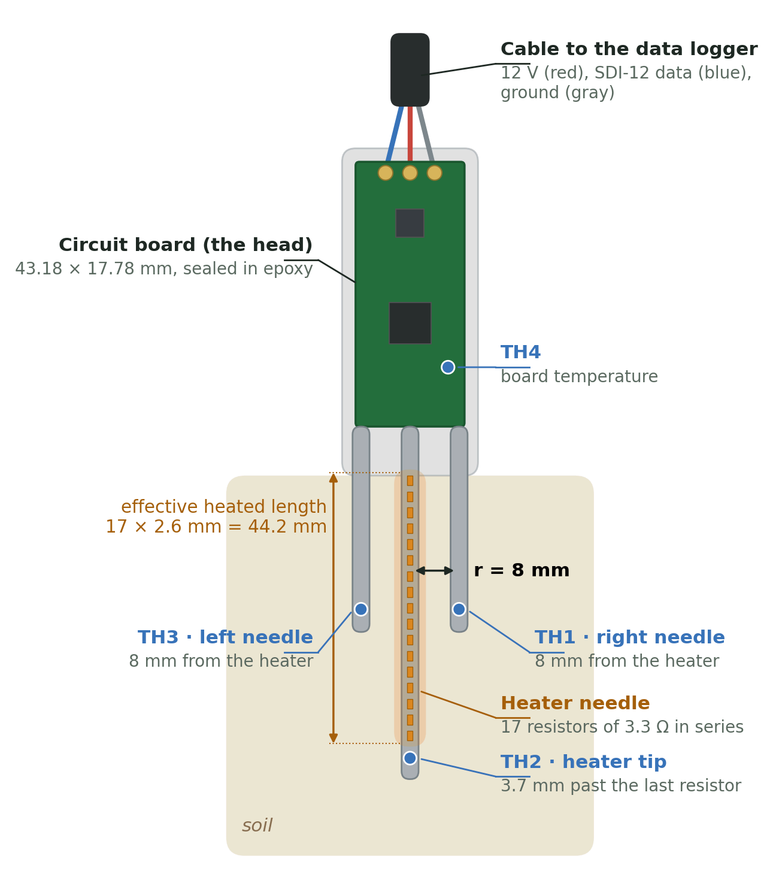
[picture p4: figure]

Figure 1. The sensor, drawn to scale (millimeters): cable end up, needles down, seen from the board's top face, the way the website draws it. The 12-gauge steel needles (2.77 mm across) slide over the board's three prongs. TH1 and TH3 sit halfway along the heated section, 8 mm from the heater; TH2 sits just past the last heater resistor. Left and right are as seen in this view.
A data logger asks for each measurement over a single data wire, using SDI-12, a standard way for environmental sensors to talk to loggers. One measurement goes like this (Figure 1 shows where each part sits):
1. Background (10 s). Record the soil temperature before heating, so we can subtract it later.

2. Heating (15 s). Push about 2 W through the heater. That is roughly the power of a small flashlight bulb, spread along 44 mm of needle.
3. Cooling (150 s). Keep recording while the heat spreads outward. The side needles warm up by about half a degree, peak about 23 s after the heater switches off, and slowly cool.
4. Analysis. How high the side-needle curve rises tells us how much heat the soil can store (its heat capacity). How fast the peak arrives tells us how fast a temperature change spreads through it (its diffusivity). Together they give the thermal conductivity, and the heat capacity gives the water content, because water stores far more heat than soil minerals or air.

Analogy. Drop a spoonful of dye into still water and watch a spot 8 mm away. In thick syrup the color arrives late and stays concentrated; in water it arrives quickly and fades fast. The heat pulse is the dye, the soil is the liquid, and the side thermistor is your eye. The one difference: we know exactly how much "dye" (energy, in joules) we released, because we measure the heater power.

Two pieces of engineering make this work: an electronic circuit that measures temperature to a few thousandths of a degree (Sections 2 and 3), and a physical model that converts the temperature curve into soil properties (Sections 4 to 6).

## 2. Electricity for soil scientists

### 2.1 Voltage, current, resistance

Three quantities describe almost everything on this board:

Quantity Symbol ·
unit
What it is | Water analogy
Voltage | · volt (V) | The "push" that drives charge, always measured
between two points

Water pressure (height difference between two tanks)
Current · ampere
(A)
How much charge flows per second | Flow rate (liters per second)
Resistance | · ohm (Ω) How strongly a part opposes the flow | A narrow section of pipe
Power | · watt (W) Energy converted per second (in a resistor: to heat) | Pressure × flow: the work the water does

Figure 2 pictures these quantities with water. Handy prefixes: 1 mA = 0.001 A, 1 µA = 0.000001 A, 1 kΩ = 1000 Ω, 1 mW = 0.001 W. Ground (GND) is simply the point we call 0 V; every other voltage on the board is measured from it, just as elevations are measured from sea level.

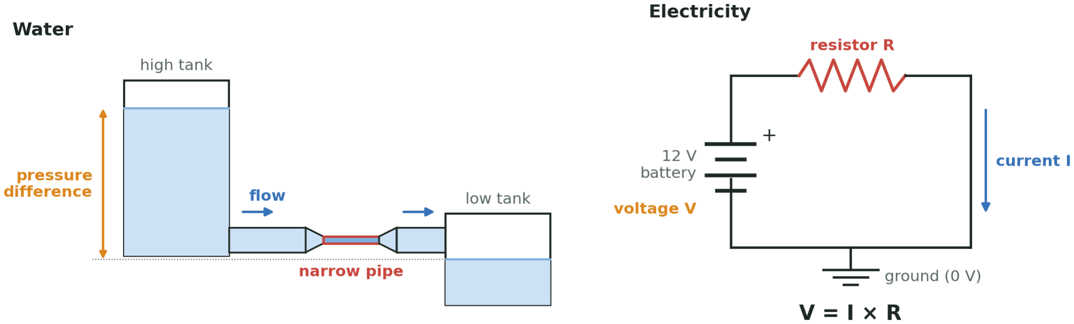
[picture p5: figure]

Figure 2. The water analogy, side by side with the circuit it stands for. The height difference between the tanks drives the flow, as the battery's voltage drives the current; the narrow pipe limits the flow and is where the energy is spent, as the resistor limits the current and turns energy into heat; the low tank is ground. This is exactly how the heater needle works.

### 2.2 Ohm's law and power, with the heater

For a resistor, current is proportional to voltage:

and the power it turns into heat is

Worked example: the heater. Seventeen 3.3 Ω resistors in a row (in series, one after the other) add up:
. If the full 12 V battery sat across the heater, the current would be | A. In

V

I

R

P

V = I R | ⟺ | I =

V
R | ⟺ | R =
I

V

P = V I = I R =

2
. R

V

2

Rheater =
17 × 3.3 = 56.1 Ω | 12/56.1 = 0.214

reality a few other things are in the same loop, and each takes its share:

Part of the loop | Resistance or drop
Input diode D1 (protects against a reversed battery) | ≈ 0.35 V drop
5 m of 22 AWG cable, out and back (10 m of wire) | ≈ 0.53 Ω
Current-sense resistor R5 (the INA226 measures the current here) | 0.10 Ω
Heater switch Q1 (a MOSFET, when on) | ≈ 0.03 Ω
Board copper in the heater loop | ≈ 0.20 Ω
Heater, 17 × 3.3 Ω | 56.10 Ω
So the heater gets | W while it is on, and each little resistor gets
W, well under its 0.33 W rating.

PWM: turning a heater "down" with a switch. We cannot easily change the battery voltage, but we can switch the heater on and off very fast. The processor will switch Q1 100 times per second and keeps it on 85% of each cycle (the duty cycle). The soil cannot feel 100 flickers per second, so it sees the average:
W. Over a 15 s pulse the energy is | J. That energy divided by the heater's
effective length, | J per meter, is the key input to the soil model in Section 5.

### 2.3 Series resistors and the voltage divider

Put two resistors in series between a voltage and ground. The same current flows through both,
, so the voltage at the point between them is
This is the voltage divider, and it is the heart of the temperature measurement: if | changes with temperature, so
does | . If | , the midpoint sits at exactly half of | .

Analogy. Water flows down a hill through two stretches of narrow pipe. The pressure halfway down depends on how the total "resistance" is split between the upper and lower stretch. Make the lower stretch narrower and more of the pressure drop happens there, so the midpoint pressure rises.

### 2.4 Capacitors and the RC time constant

A capacitor stores electric charge, like a small bucket. Its size, the capacitance , is measured in farads (F); ours are
100 nF (0.0000001 F) and 1 µF. The charge it holds is | : a bigger bucket, or a fuller one, holds more.
A capacitor does two useful jobs: it smooths (it absorbs sudden spikes and fills in brief dips, like a water tower on a town's water line), and together with a resistor it sets a delay. If you fill a capacitor through a resistor from a voltage , it charges along
I = | =
56.10 + 0.53 + 0.10 + 0.03 + 0.20 Ω

### 12 V − 0.35 V

≈
56.96

11.65
0.2045 A

P = I

2R = 0.2045

2 × 56.1 = 2.35 | 0.2045

2 ×
3.3 = 0.138

0.85 × 2.35 = 1.99
E = P t = 1.99 × 15 ≈ 29.9

### 29.9 J/0.0442 m ≈ 677

Vtop | I =
Vtop/(R1 + R2)
Vmid = I R2 = V | . top R1 + R2

R2

R2
Vmid | R1 = R2 | Vtop

C
Q = C V

R
V0
V (t) = V0 (1 − e | , | τ =
−t/τ) | R C.

The time constant is the whole story: after one the capacitor is 63% full, after 5 it is 99.3% full, and after 10 it
is within 0.005% of its final value. Example: 1.5 kΩ and 1 µF give | ms.

Analogy. Filling a bathtub through a garden hose. The tub is the capacitor, the hose is the resistor. A thinner hose (more R) or a bigger tub (more C) means a longer wait. The tub fills fast at first and slows as it nears full, because the pressure difference that drives the flow shrinks. That is the exponential curve above.

## 3. The thermistor circuit, part by part

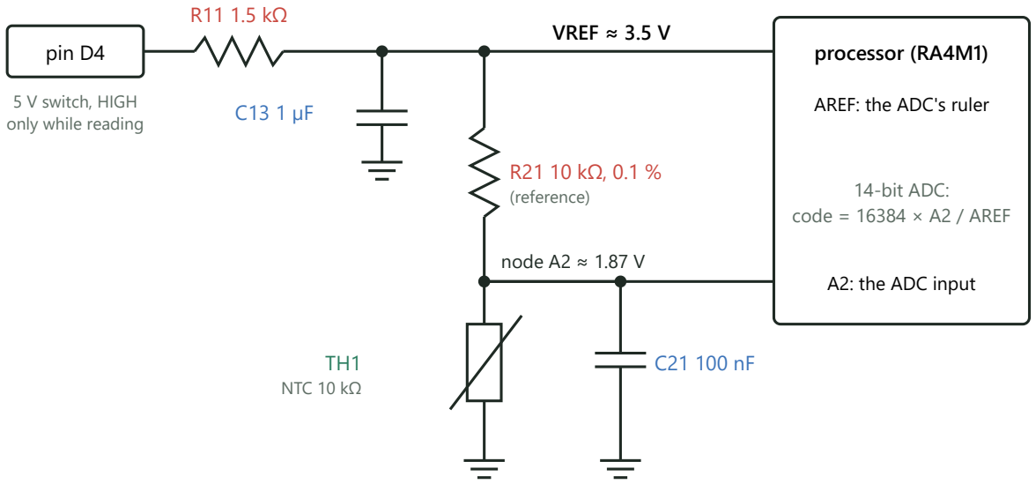
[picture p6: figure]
pin D4; 5 V switch, HIGH only while reading; VREF ≈ 3.5 V; R21 10 kΩ, 0.1 % (reference); TH1 NTC 10 kΩ; node A2 ≈ 1.87 V; processor (RA4M1); AREF: the ADC's ruler; A2: the ADC input; 14-bit ADC: code = 16384 × A2 / AREF

the same divider is repeated four times: R21–R24, TH1–TH4, C21–C24 (A2, A1, A0, A3)

Figure 3. One of the four thermistor channels. Pin D4 powers VREF through R11; C13 holds VREF steady. VREF feeds the reference resistor R21 on top and the thermistor TH1 below it, and the same VREF is the processor's measuring "ruler" (AREF). C21 steadies the node that the processor reads.

### 3.1 The thermistor

A thermistor is a resistor made to change its resistance with temperature. Ours are "NTC" (negative temperature coefficient): warmer means lower resistance. At 25 °C it is nominally 10 kΩ (±1%). The standard "beta" equation describes it:

with in kelvin (°C + 273.15). Near room temperature the resistance changes by about | per degree,
which is large; that is why thermistors are good at sensing small temperature changes (Figure 4, left).
τ | τ | τ | τ
τ = 1500 × 0.000001 = 1.5
R(T) = R25 exp[β ( − | , | R =
T

1
298.15 K
1 | )] | 25 | 10 kΩ, β = 3380 K,

T β/T

| | | 2 ≈ 3.8%

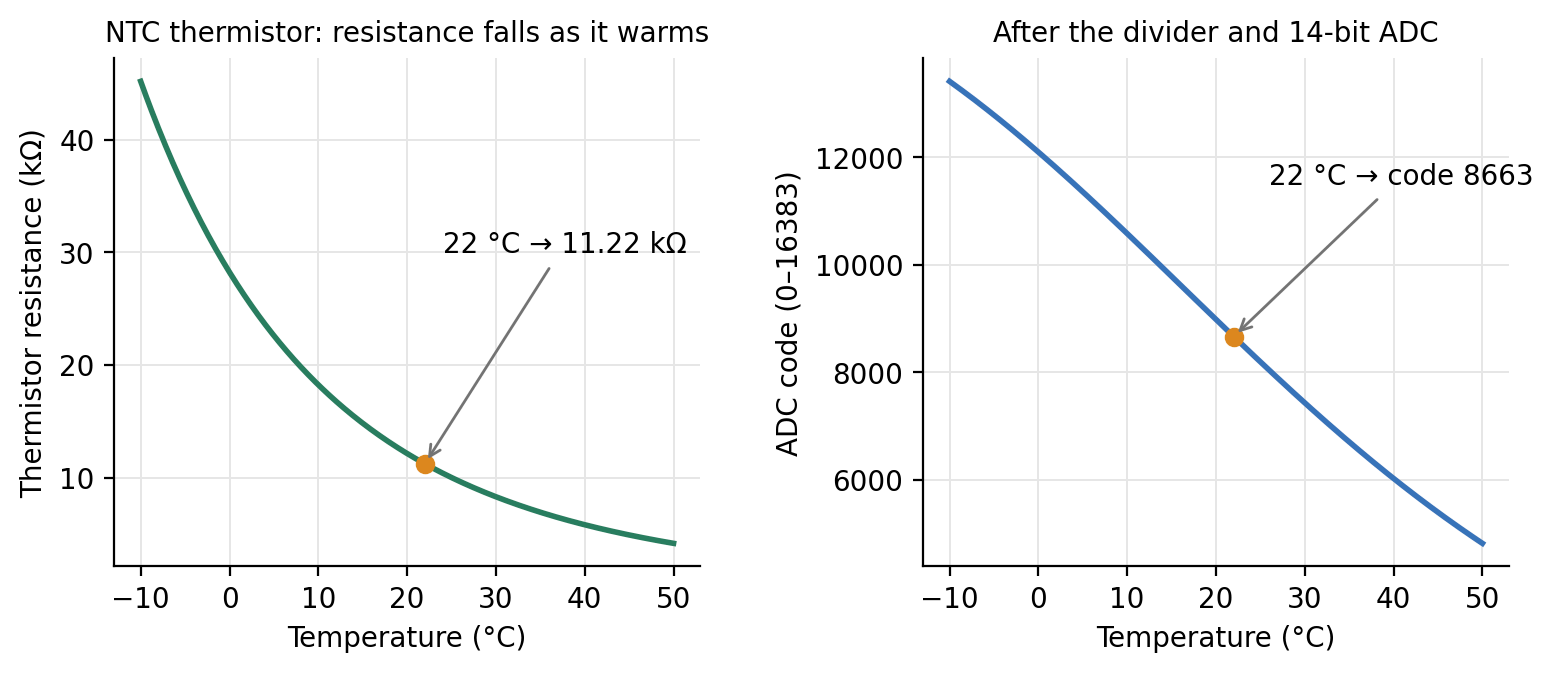
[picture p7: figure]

Figure 4. Left: resistance of the thermistor. At 22 °C it is 11.22 kΩ. Right: the number the processor sees after the divider and the analog-to-digital converter (Sections 3.2 and 3.3).

### 3.2 Why a reference resistor (R21–R24)?

The processor cannot measure resistance. It can only measure voltage. The reference resistor turns a resistance into a voltage by forming a divider with the thermistor (Section 2.3; Figure 3):

Example at 22 °C: | kΩ, | kΩ, | V, so the current is
and | V. Warm the soil and the thermistor's resistance drops, so the node
voltage drops.
Why 10 kΩ? Choosing the reference equal to the thermistor's nominal value puts the node near half of VREF, where the divider is most sensitive to small changes. Why 0.1% precision and 25 ppm/°C? Any error in the reference resistor looks exactly like a temperature error. A 1% resistor would shift the reading by about 1%/3.8% ≈ 0.26 °C; the 0.1% part keeps that below 0.03 °C, and its low temperature coefficient keeps it from drifting as the board warms or cools. For the soil properties, what matters is the temperature rise, and a fixed offset cancels when the background is subtracted: a 1% reference error changes the rise by only about 0.2%. The thermistor's value is different: an error in scales every rise, and therefore and , one for one.
Does the divider linearize the thermistor? Only as a side effect. The right panel of Figure 4 is not an approximation of the left one: it is the exact result, code = 16384 × R / (R + 10 kΩ). The fraction R / (R + Rref

) flattens toward 1 when
the thermistor resistance is large and toward 0 when it is small, which counteracts the thermistor’s steep exponential curve. The result is an S-shaped curve that is nearly straight around the temperature where the thermistor equals the reference resistor (25 °C here) and bends more toward cold and hot temperatures. The processor never uses a straight-line approximation: it inverts the exact divider and beta equations (Section 3.3), which costs only a few lines of arithmetic. What the divider’s shape buys is nearly even resolution across the range of soil temperatures:
Vnode = VREF | . Rref + RNTC

RNTC

RNTC = 11.22 | Rref = 10 | VREF = 3.53 | 3.53/21.22 kΩ = 166 μA
Vnode = 3.53 × 11.22/21.22 = 1.87

β
β | λ | C

Temperature | Thermistor | ADC code | Codes per °C | °C per code
-10 °C | 45.2 kΩ | 13414 | 119 | 0.0084 °C
0 °C | 28.2 kΩ | 12098 | 143 | 0.0070 °C
10 °C | 18.2 kΩ | 10581 | 158 | 0.0063 °C
22 °C | 11.2 kΩ | 8663 | 158 | 0.0063 °C
25 °C | 10.0 kΩ | 8192 | 156 | 0.0064 °C
40 °C | 5.8 kΩ | 6021 | 131 | 0.0076 °C
50 °C | 4.2 kΩ | 4813 | 110 | 0.0091 °C
60 °C | 3.0 kΩ | 3819 | 89 | 0.0112 °C
Near-surface soil can reach 50–60 °C in summer, especially while the heater is on. Even at 60 °C one code is about 0.011 °C, about 45 times finer than the half-degree signal. A smaller reference resistor would move the flattest part of the curve to warmer temperatures: with 6.8 kΩ, the value matching the thermistor at about 35 °C, resolution at 60 °C improves by about 20% but is about 13% worse at 10 °C, and the dividers draw more current, which lowers VREF and adds a little self-heating. Because noise, not the number of ADC steps, will limit the measurement, 10 kΩ remains a sound choice for the whole 0–60 °C range.

### 3.3 From voltage to a number: the ADC

The processor's analog-to-digital converter (ADC) compares the input voltage with a reference voltage and reports
a whole number, the code. With 14 bits there are | steps:

Here is the trick in this design: the ADC's reference (AREF) is connected to the same VREF that feeds the dividers. Substitute the divider equation and VREF cancels:

Analogy: a stretchy ruler. Measure a rubber band with a ruler printed on the same rubber. If both stretch together, the reading does not change. This is called a ratiometric measurement: VREF can sag or drift a little and the temperature reading stays the same, because the "ruler" (AREF) and the "object" (the divider) move together.

Worked example. At 22 °C: code = 16384 × 11.22/21.22 = 8663. Going back:
kΩ, and inverting the beta equation,

How fine is the measurement? Near 22 °C the code changes by about 158 codes per °C, so one code is about 0.006 °C. The planned firmware averages 64 readings per sample (the twin assumes this), which reduces random noise further. The signal we want, the side-needle rise, is about 0.5 °C, or roughly 80 codes. The real limits are noise, thermistor calibration and the reference resistor, not the number of steps.

2 =

14 16384

code = 16384 × .
VAREF

Vnode

code = 16384 × | ⇒ Rref + RNTC
RNTC | RNTC = R | . ref 16384 − code

code

R = 10 kΩ × 8663/(16384 −
8663) = 11.22
T = [ | + | −
β

ln(R/R25)
298.15

1
]

−1
273.15 = [ | + | −
3380

ln 1.122
298.15

1
]

−1
273.15 = 22.0 C.

∘

### 3.4 Why the thermistors are switched on only to read

Current through a thermistor heats it. This self-heating is a real problem when the signal is half a degree. During a reading the thermistor carries 166 µA with 1.87 V across it:

The maker quotes a "dissipation constant" of about 1 mW/°C in still air, so 0.31 mW would warm the thermistor by about 0.3 °C; in epoxy and soil heat escapes more easily, so the real warming is smaller. Left on all the time, that would be a steady warming comparable to the signal. A perfectly steady offset would cancel when the background is subtracted, but this one would not be steady: it depends on how well the thermistor is coupled to the soil, which changes with moisture, and it warms the very spot being measured. So pin D4 powers the whole thermistor network only 20 ms out of every second (2%). The average heating power drops to about 6 µW, and the self-heating to a few thousandths of a degree. It also saves battery.

Analogy. Checking whether bread is done by touching it: a quick tap tells you the temperature; holding your hand on it warms the bread. The thermistors get a quick tap once per second.

### 3.5 Why R11 (1.5 kΩ)?

Pin D4 is a processor output, and processor pins are delicate: the RA4M1 data sheet lists 4 mA per pin for this port (Arduino's Nano R4 documentation quotes up to 8 mA; the design uses the more conservative data-sheet value). When D4 switches on, C13 is empty and behaves for an instant like a short circuit to ground. Without a resistor the pin would try to deliver a large current. R11 limits it by Ohm's law:

(An earlier version used 330 Ω, which would have allowed about 14 mA; that is why it was changed.) Once C13 is charged, R11 carries the steady current of the four dividers plus the ADC reference, about 0.8 mA. That current makes
a voltage drop across R11, | V, which is why VREF settles near 3.5 V rather than 4.75 V.
Thanks to the ratiometric trick, that lower value does not matter.

### 3.6 Why C13 and C21–C24?

C13 (1 µF) holds VREF steady. The ADC draws small, quick sips of current from its reference while it converts. Without a local "bucket," each sip would dent VREF through R11. C13 supplies the sips and refills between them. With R11 it charges with a time constant of about 1.1 ms (R11 in parallel with the divider load, times 1 µF).
C21–C24 (100 nF each) hold each thermistor node steady. Three reasons:
1. The ADC takes a gulp. Inside the ADC, a tiny capacitor is connected to the input for a moment and must be charged to the input voltage. Through 5 kΩ of divider resistance, that gulp would pull the voltage down briefly. The 100 nF capacitor is thousands of times larger than the ADC's internal one, so it supplies the gulp with almost no change in voltage.
2. The needle wires are antennas. The thermistor wires run 30 to 55 mm down the needles, right next to a heater that switches 100 times per second. They pick up electrical noise. The capacitor, together with the divider resistance, forms a filter that smooths out fast disturbances while passing the slow temperature signal.
3. A known, short settling time. Each node settles with
ms. The planned firmware waits 10 ms before reading. That is nearly 19 of the node's own

P = V I = 1.87 V × 166 μA ≈ 0.31 mW.

Ipeak = | =
1500 Ω

### 4.75 V

3.2 mA < 4 mA.

1500 Ω × 0.8 mA ≈ 1.2

τ = (10 kΩ ∥ RNTC) × 100 nF ≈ 5.3 kΩ × 100 nF = 0.53 time constants, but the node also follows VREF, which settles more slowly (about 9 of its time constants in 10 ms). The node-to-VREF ratio is within about one ADC step at the first reading and closer on average, and the small remainder is the same every second, so it cancels when the background is subtracted.

Why not bigger capacitors? Bigger capacitors would smooth more but take longer to charge, so pin D4 would have to stay on longer (more self-heating) and the network would need longer to discharge between readings. The values are a balance between steadiness and speed.

### 3.7 One reading, millisecond by millisecond

This is the planned sequence that the twin simulates (Figure 5); the firmware is still to be written.

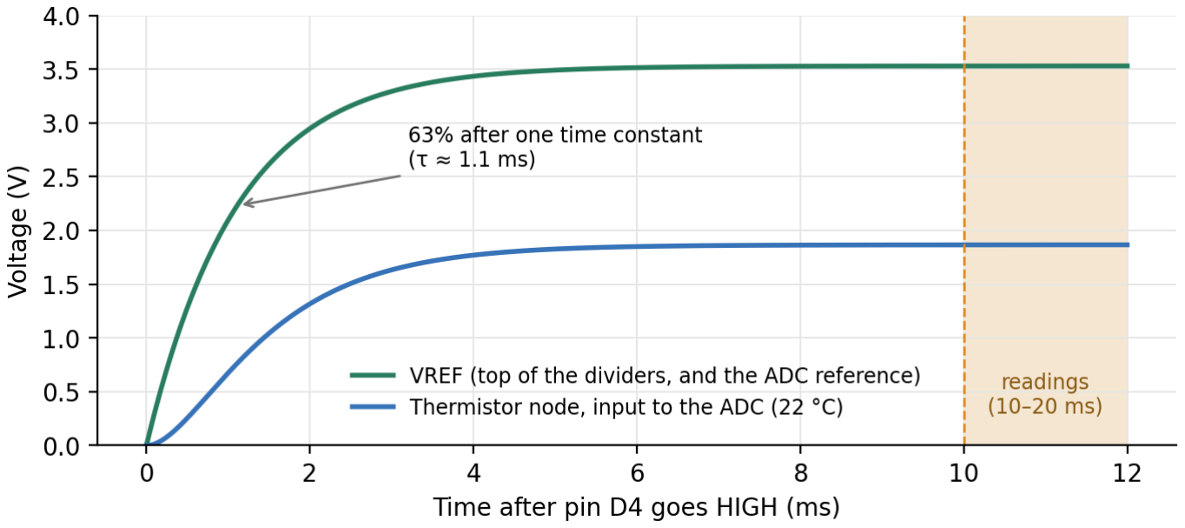
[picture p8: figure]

Figure 5. After pin D4 goes HIGH, VREF rises with a time constant of about 1.1 ms, and the thermistor node follows a little later through its own 0.53 ms filter. Both are flat long before the readings start at 10 ms. At 20 ms pin D4 goes LOW and everything discharges until the next second.

Time | What happens
0 ms | Pin D4 goes HIGH. R11 limits the inrush into C13 to 3.2 mA.
0–10 ms | VREF and the four thermistor nodes charge and settle (about 9 and 19 time constants).
10–20 ms The ADC takes 64 readings of each of A0–A3 and averages them.
20 ms | Pin D4 goes LOW; the network discharges. The thermistors rest for the remaining 980 ms.
every 1 s | Repeat, through the background, heating and cooling phases.

### 3.8 Where the parts sit on the board

Everything in Sections 2 and 3 is a real part you can find on the board. Figure 6 shows the whole sensor as KiCad renders it, turned the way the website draws it: cable end up, needles down, seen from the top face (so TH1 is on the right). Figure 7 zooms in on the head. Every part is marked with a dot and its name, each color is one job, and the text beside each group says in a sentence what it does and which section explains it. Appendix A lists every part with its manufacturer, part number and specifications.

Color | Job | Where the theory is
Orange Power coming in from the battery, and its protection | Section 2.2 (Ohm's law around the heater loop)
Gold | Making and distributing the 5 V for the electronics | Section 2.4 (capacitors as buckets)
Blue | The processor and its programming holes | Section 3.3 (the ADC lives inside U1)
Teal | The SDI-12 line to the data logger | Section 1; tour step 9 on the website
Pink | Temperature measurement: the thermistor circuit of Figure
| 3 | Sections 3.1–3.7
Red | The heater: switching it and measuring the power it delivers | Sections 2.2 and 5.5 ( comes from U4's measurement)

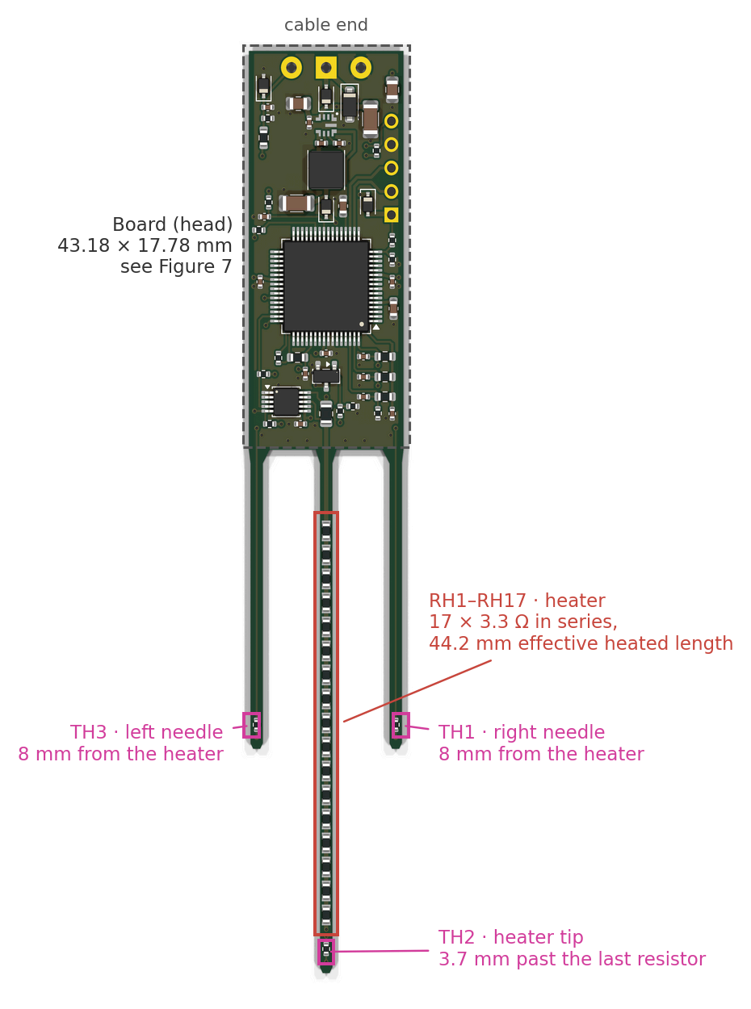
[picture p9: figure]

Figure 6. The whole sensor (KiCad render of the current board). The heater's 17 resistors run down the center needle; TH1 and TH3 sit on the side needles halfway along the heated section, and TH2 sits just past the last resistor. The dashed box is the head, enlarged in Figure 7.

q

′

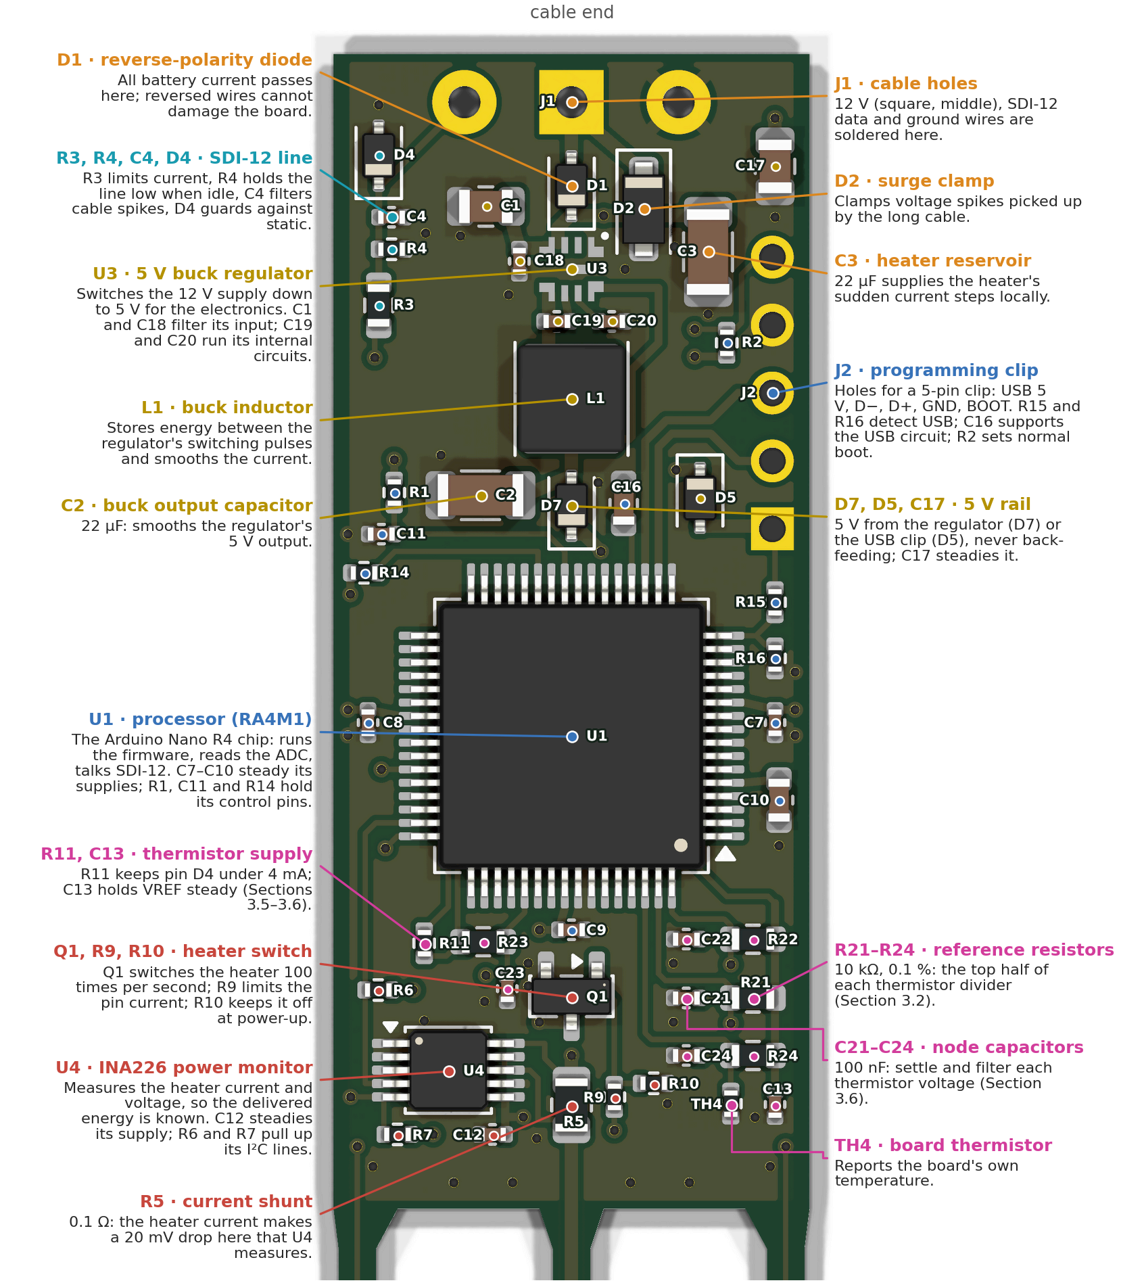
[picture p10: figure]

Figure 7. The head, part by part. Every part is marked with a dot and its name (the names are the ones used throughout this chapter and in Appendix A). Dots of one color belong to one job (the colors follow the table in Section 3.8); the line from each description ends on the group's main part, the larger dot. TH1–TH3 and the heater resistors sit on the needles (Figure 6). The measurement parts (pink) sit together near the needles, away from the switching regulator at the cable end, and the parts that warm up in use (U1, U3, L1, D1, D7, R5, Q1) sit on the board’s center line, so they warm both side needles equally.

## 4. Heat in soil

Three properties describe how a material handles heat:

Property | Symbol · unit | Meaning | Analogy
Thermal conductivity | · W m⁻¹ K⁻¹ | How easily heat flows through it | How wide the pipes are
Volumetric heat capacity | · J m⁻³ K⁻¹ (MJ m⁻³ K⁻¹) | Energy needed to warm 1 m³ by 1 °C | How big each bucket is
Thermal diffusivity | · m² s⁻¹ (mm² s⁻¹) | How fast a temperature change spreads | Wide pipes into small buckets: news travels fast

Soil is a mix of minerals, organic matter, water and air, and the mix sets the properties:

Material | (W m⁻¹ K⁻¹) | (MJ m⁻³ K⁻¹)
Water | 0.6 | 4.18
Air | 0.025 | 0.0012
Quartz | ≈ 8 | ≈ 2.0
Other soil minerals | ≈ 2–3 | ≈ 2.0
Dry soil (typical) | 0.2–0.5 | 1.0–1.4
Moist soil (typical) | 1.0–2.0 | 2.0–3.2
The key fact for water content: water has twice the heat capacity of minerals and three thousand times that of air. When a soil gains water, the water replaces air, and the heat capacity climbs linearly with the water content. Measure , and you can back out the water content (Section 5.6).

## 5. The line-source model

### 5.1 The heat equation

Heat flows from warm to cold at a rate proportional to the temperature gradient (Fourier's law), and energy is conserved. Combining the two gives the heat equation:

In words: a spot warms up if it is colder than the average of its surroundings, and the rate is set by the diffusivity. For a long, straight heater it is natural to use distance from the heater, , as the coordinate; if nothing changes along the heater's length, the equation becomes

The extra term appears because heat spreads over ever-larger rings: a ring twice as far away has twice the circumference to warm.

λ

C

α = λ/C

λ | C

C

=
∂t

∂T
α ∇ T, α =

2
. C

λ

r

=
∂t

∂T
α ( + .
∂r

2

∂ T

2
r

1
∂r

∂T )

1/r

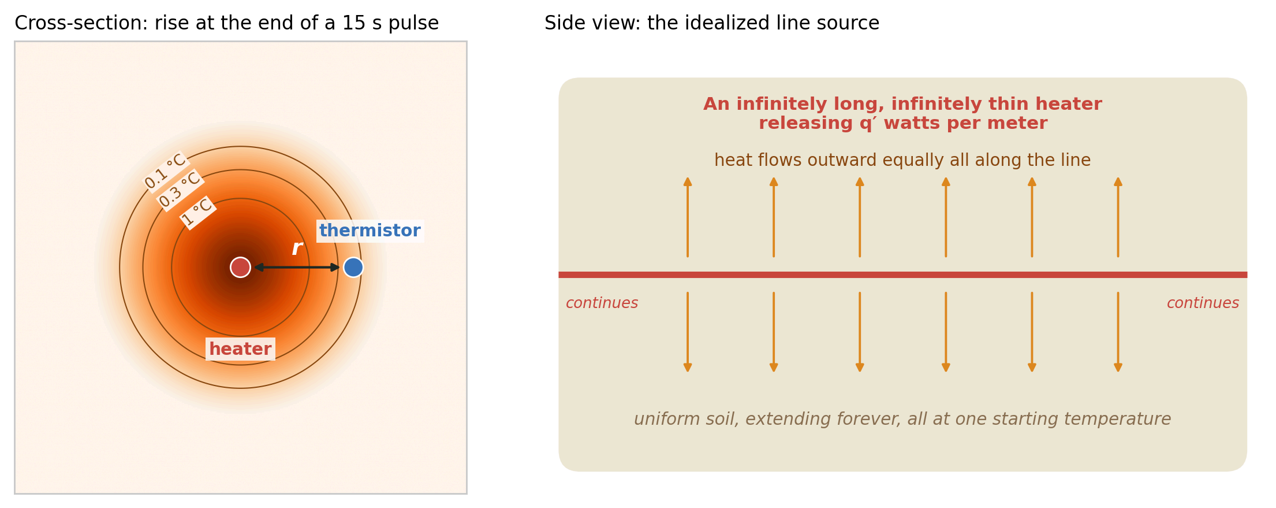
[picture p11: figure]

Figure 8. The idealized picture behind the line-source model. Left: temperature rise in a cross-section around the line at the end of a 15 s pulse (medium soil, rings at 0.1, 0.3 and 1 °C); the thermistor, 8 mm away, has warmed by about 0.13 °C so far and keeps warming after the heater stops. Right: the assumptions of Section 5.2 in one picture.
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

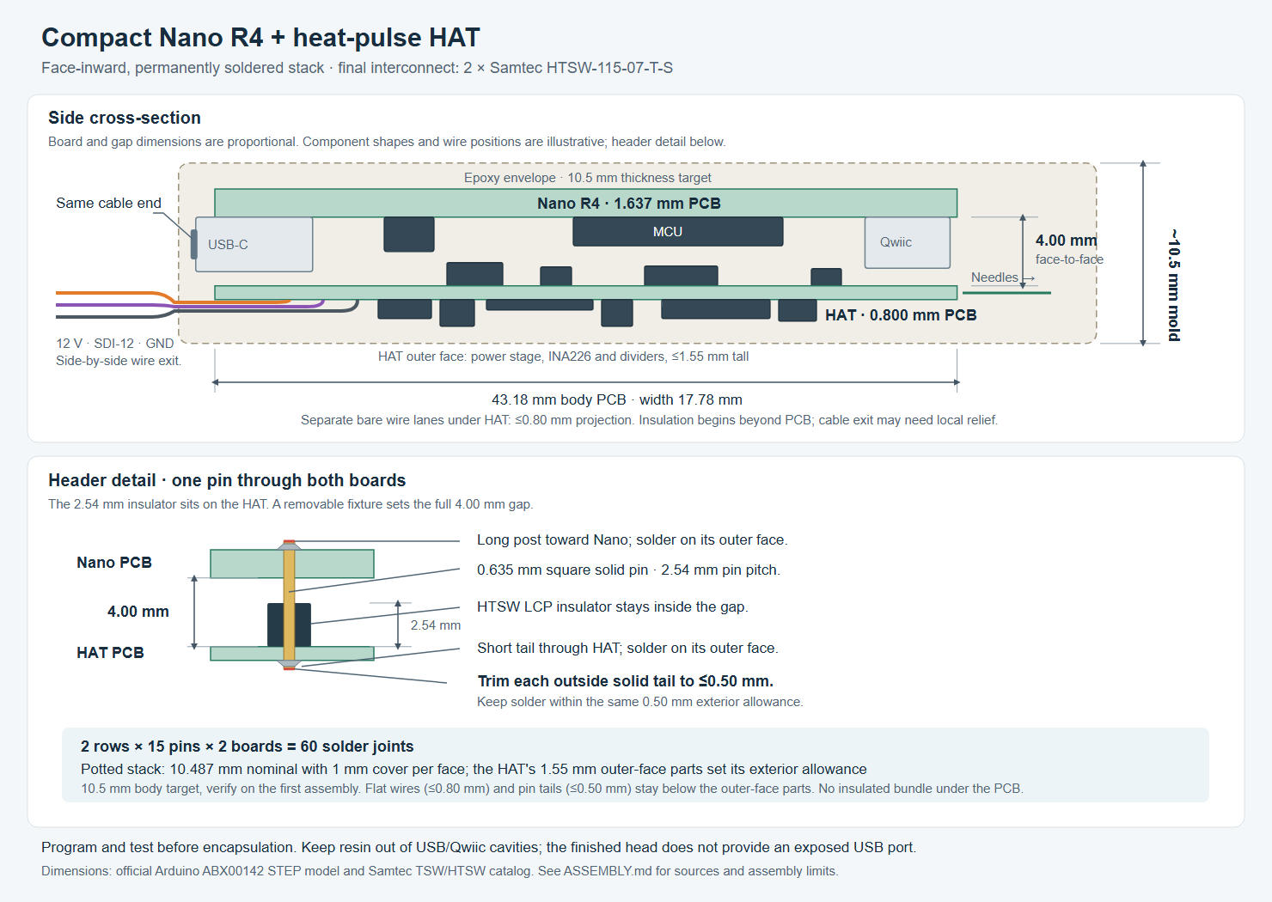
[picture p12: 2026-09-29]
hat/mechanical/nano-hat-stack.png

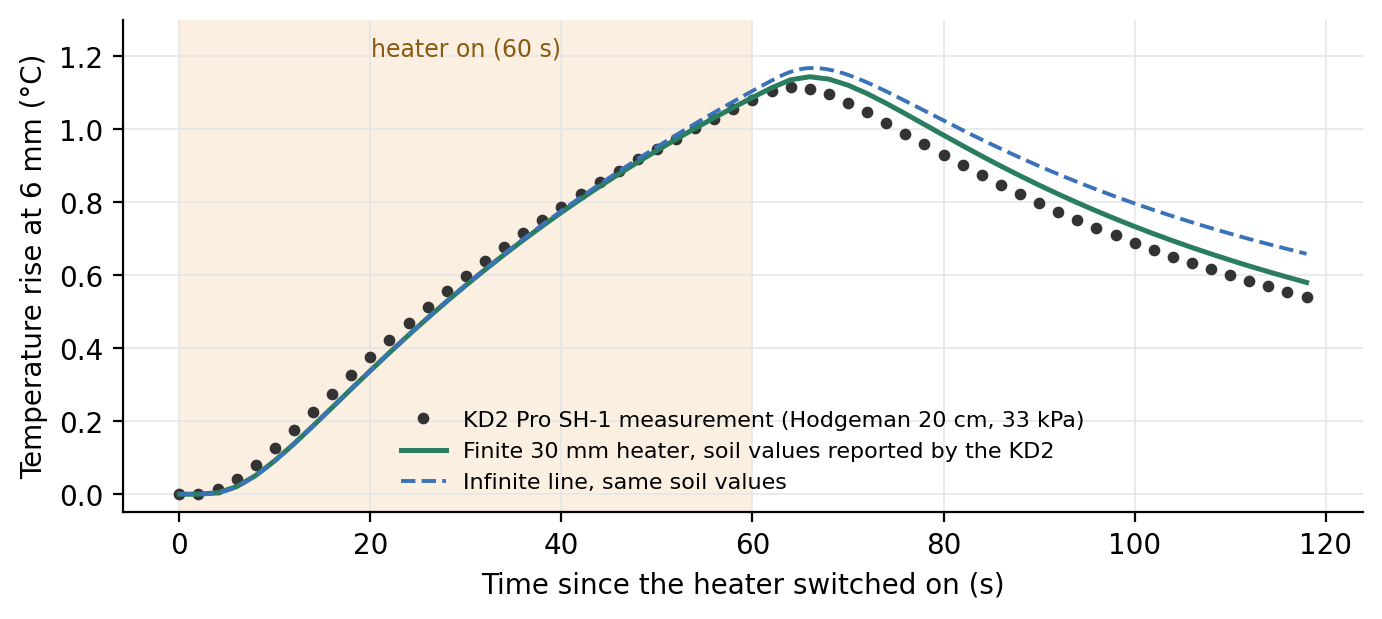
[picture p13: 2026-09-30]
docs/primer/fig/kd2.png

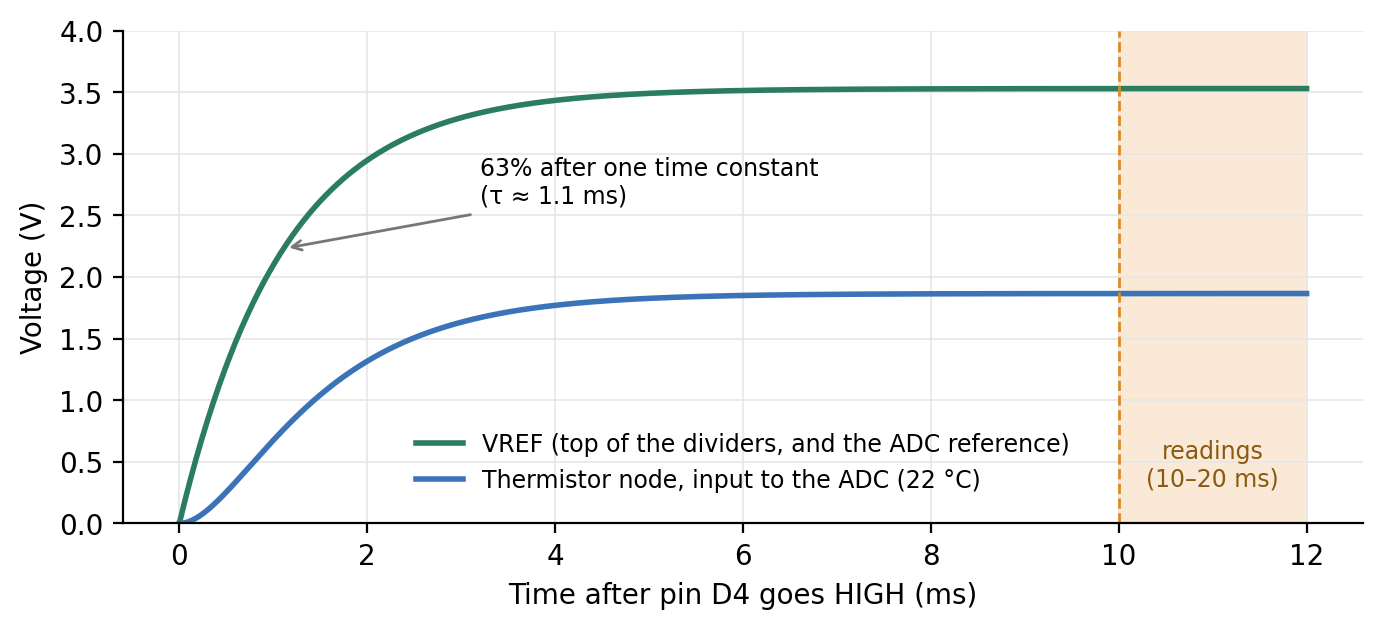
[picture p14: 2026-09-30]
docs/primer/fig/rc.png

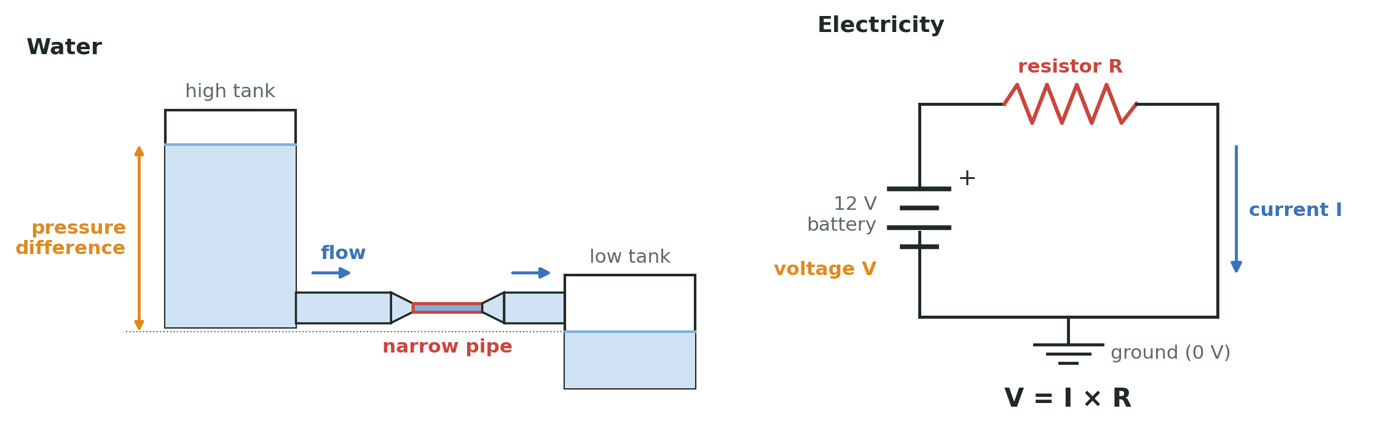
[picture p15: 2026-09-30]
docs/primer/fig/water.png

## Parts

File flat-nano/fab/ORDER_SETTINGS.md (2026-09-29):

# HP-SDI12-NANO — JLCPCB order settings

Use these three files together from this folder:

- `HP-SDI12-NANO_gerbers.zip`
- `HP-SDI12-NANO_BOM.csv`
- `HP-SDI12-NANO_CPL.csv`

| Setting | Selected value |
| --- | --- |
| Material / layers | FR-4 / **4 layers** |
| Finished thickness | **0.8 mm nominal**; retain this thickness for needle fit |
| Standard construction | **JLC04081H-7628**, the default 0.8 mm, 1 oz outer / 0.5 oz inner stack |
| Copper weight | **1 oz outer / 0.5 oz inner** |
| Finish | **lead-free HASL** |
| Solder mask / legend | **Green / white** |
| Via covering | **Tented**, both sides; retain the supplied mask openings over cable/programming holes |
| Impedance control | **No controlled-impedance requirement** |
| Assembly | **Standard PCBA, top side only** |
| Bare-PCB factory electrical test | **Yes**; separate from the optional assembled-board flying-probe service below |
| Additional marking | Keep order/traceability marks on the electronics body, clear of pads and labels; none on the needle prongs |
| Delivery | Individual assembled sensors, depanelized, with smooth needle-insertion edges |

The single PCB outline is **99.86 × 17.78 mm**; the electronics body is **43.18 × 17.78 mm**, the Arduino Nano R4 outline. Request **custom panel design through JLCPCB engineering** for this fork-shaped outline. The ordinary automatic **Panel by JLCPCB** option is intended for rectangles/circles and is not suitable here. Use the supplied single-sensor files as the source for the custom temporary manufacturing panel. Standard PCBA requires at least 70 × 70 mm; simply adding 5 mm rails to this narrow board is insufficient. Do not enlarge the finished sensor to satisfy panel dimensions. Economic PCBA does not support this exact four-layer, 0.8 mm construction.

Select **LeadFree HASL** in the surface-finish selector. This is the lower-cost lead-free finish selected for this release.

## Advanced PCBA options

| Option | Select | Reason / instruction |
| --- | --- | --- |
| Bake Components | **No** | No blanket extra bake; required component moisture/floor-life handling still applies. |
| Board Cleaning | **No** | This corrects the earlier recommendation. The Murata NCP15 thermistors must not be cleaned after no-clean flux. No solvent, dry-ice or ultrasonic whole-board cleaning. |
| Special stencil | **No** | No special stencil process is specified for this design. |
| Depanel boards & edge rail before delivery | **Yes** | Deliver individual sensors; remove support remnants flush without bending the prongs or damaging components. |
| Flying Probe Test | **No** | Optional assembled-board service omitted for this cost-conscious first order. Keep the separate bare-PCB electrical test enabled. |
| Function test | **No** | No factory functional-test procedure, programming package or test equipment is supplied with these files. Bench-test every assembled sensor before potting. |
| Photo Confirmation | **No** | Omit the paid photo service to reduce cost. Review the online placement preview and inspect the boards after delivery. |
| Conformal Coating | **No** | Keep solder/programming features accessible. Needle insulation and potting are later operations, with material compatibility checked on hardware. |
| Packaging | **Antistatic bubble film** | Request rigid protection for the slender prongs in the remark. |
| Solder Paste | **High temp.** | Lead-free solder with compatible rosin-based no-clean flux; do not select medium/low-temperature paste. |
| Nitrogen reflow soldering | **No** | Do not add this optional surcharge for the current assembly. |
| Assembly remark | **Yes** | Paste only the paragraph below; it fits the 500-character field. |

The optional assembled-board flying-probe service adds checks of component values and assembly connections and requires additional test data (ODB++ for other CAD tools). It is not equivalent to the bare-PCB electrical test and does not replace firmware/communication/heating checks. See [JLCPCB personalized services](https://jlcpcb.com/help/article/jlcpcb-supported-personalized-services). The choices above also follow the factory's [moisture-handling guidance](https://jlcpcb.com/blog/moisture-sensitivity-level-msl-baking-guide), [solder-paste guidance](https://jlcpcb.com/help/article/medium-low-temperature-solder-paste-service), and [reflow guidance](https://jlcpcb.com/blog/reflow-soldering).

## Assembly remark - 357 characters

Copy only this paragraph:

> HP-SDI12-NANO: exact BOM/CPL; RH1-RH17=C313752, 0.33W only. Top assembly; J1/J2 bare. Custom panel; preserve outline, 4 layers, 0.8mm. Deliver depanelized; tabs flush on 1.4mm prongs; no prong markings. Lead-free HASL/solder, rosin no-clean flux. DO NOT CLEAN: Murata NCP15. No solvent, dry ice, ultrasonics or coating. Protect prongs with rigid packing.

All 68 fitted parts belong on the top side. The placement file includes the package rotation corrections for the specified JLCPCB parts; confirm the orientation of the new parts (U3, the TI buck regulator, and the SOD-323 diodes D1, D5 and D7) in the assembly preview. The three bare cable holes are +12 V, SDI-12 signal, and ground; underside labels and the square positive-supply pad identify them.

Use the exact BOM parts, especially the 17 × 3.3 ohm Vishay CRCW06033R30FKEAHP 0.33 W heater resistors (C313752), Murata thermistors, reference resistors, current shunt, TI LMR36503R5RPER buck regulator and its Sunlord 22 µH inductor. Do not substitute a lower-power heater resistor. Review pin-1 and diode polarity in the assembly preview.

## Cleaning method - no factory wash

Select **Board Cleaning: No** for this BOM. [JLCPCB normally uses no-clean solder paste](https://jlcpcb.com/help/article/terms-and-conditions-of-jlcpcb-assembly-service). For TH1-TH4, Murata NCP15XH103F03RC, the [manufacturer's specification](https://www.murata.com/-/media/webrenewal/products/thermistor/ntc/ncp/ncp15.ashx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), pages 13 and 18, explicitly excludes cleaning after no-clean flux. Its separate IPA cleaning conditions do not override that exclusion. Use compatible rosin-based no-clean flux; water-soluble flux is excluded by that specification.

Do not choose dry ice, solvent or ultrasonic cleaning for the assembled board. This is a component-specific process decision, not a claim that these methods are unsuitable for every PCB.

## Assembly after delivery

Hand-solder 22 AWG cables and anchor the cable jacket so pull does not load the PCB pads. Use a small amount of compatible electronics no-clean flux. If cable-joint residue requires removal, clean only the cable-pad area with a compatible electronics flux remover and prevent liquid from reaching the thermistors; do not immerse or spray the whole sensor. Let the treated area dry fully. This replaces the earlier generic instruction to clean the whole assembly.

Use a measured minimum 2.16 mm steel-needle bore and a total radial insulating liner no thicker than 25 µm (including adhesive, no overlap at the PCB). All three revised PCB prongs are 1.4 mm nominal. Dry-fit a completed, insulated prong before potting: solder height, PCB tolerance, insulation and actual bore all matter. Electrically insulate copper from the steel and encapsulate the electronics and cable entry for soil exposure. Select a potting process compatible with the remaining no-clean residues. Murata requires evaluation of resin effects on the mounted thermistors; check readings before and after curing and evaluate moisture/thermal exposure on a first finished sensor before encapsulating the batch. Solder mask and the surface finish are not waterproof encapsulation.

These files have been checked as CAD/manufacturing outputs. First-unit programming, communication, current measurement and heating checks are still required on the assembled hardware before field deployment.

Sources: [JLCPCB stackups](https://jlcpcb.com/impedance), [PCB capabilities](https://jlcpcb.com/capabilities/Capabilities), [assembly capabilities](https://jlcpcb.com/capabilities/pcb-assembly-capabilities), [automatic panel restrictions](https://jlcpcb.com/help/article/instructions-for-ordering), [custom panel engineering support](https://jlcpcb.com/blog/pcb-panelization), [via covering](https://jlcpcb.com/help/article/pcb-via-covering).

## Revised heater

The heater is 56.1 Ω total, with roughly twice the original flat board's heating capacity at 12 V. Use 11.5–14.4 V externally; the proposed 2 W, 100 Hz PWM control and 15 s shutdown must be implemented and tested in firmware. No firmware is supplied to JLCPCB. See [HEATER.md](../HEATER.md) before powering or potting assembled sensors.

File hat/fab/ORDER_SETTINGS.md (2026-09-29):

# HP-HAT — JLCPCB order settings

Upload `HP-HAT_gerbers.zip`, `HP-HAT_BOM.csv` and `HP-HAT_CPL.csv` from this folder together.

| Setting | Selected value |
| --- | --- |
| Material / layers | FR-4 / **4 layers** |
| Finished thickness | **0.8 mm nominal**; required for the preserved needle geometry |
| Standard construction | **JLC04081H-7628** |
| Copper | **1 oz outer / 0.5 oz inner** |
| Surface finish | **LeadFree HASL** |
| Mask / legend | **Green / white** |
| Vias | **Tented on both sides**, keep cable and header holes open |
| Controlled impedance | **No** |
| Assembly | **Standard PCBA, both sides** (28 top, 21 bottom) |
| Prototype quantity | **5 bare boards, 2 assembled** |
| Bare-PCB electrical test | **Yes** |
| Delivery | Individual boards, depanelized, with smooth needle insertion edges |
| Additional marks | On the body only, clear of pads and labels; none on prongs |

Finished outline: **99.86 × 17.78 mm**, including prongs. Body: **43.18 × 17.78 mm**, the exact Arduino Nano R4 outline. Ask JLCPCB engineering to make a temporary custom support panel for this fork outline; retain the finished outline exactly. Standard PCBA needs a panel at least 70 × 70 mm, so simply adding narrow rails is insufficient. The ordinary automatic panel option does not suit this fork outline. Two-sided assembly and this 0.8 mm four-layer stack both require Standard PCBA; Economic PCBA does not offer them. See [assembly capabilities](https://jlcpcb.com/capabilities/pcb-assembly-capabilities) and [panel ordering instructions](https://jlcpcb.com/help/article/instructions-for-ordering).

The BOM contains **49 parts: 28 on the top face and 21 on the bottom face**. The Gerber package includes paste layers for both faces. **J1/J3/J4 stay empty at the factory.** Buy a headerless Nano R4 ABX00142 and two Samtec HTSW-115-07-T-S strips separately and assemble using the [4 mm gap instructions](../mechanical/ASSEMBLY.md). Do not replace these with tall female sockets or install the Nano face outward.

## Placement preview (both faces)

JLCPCB shows a placement preview for each face before payment. The CPL already includes the rotation corrections for the MSOP-10 and SOT-23 packages. Bottom-face rows follow JLCPCB's bottom-view convention: 180° minus the KiCad angle, plus the same package correction. On the preview, confirm these polarized parts against the renders `render_top.png` and `render_bottom.png`:

- **Top face:** no polarized parts; D4 is a bidirectional ESD diode.
- **Bottom face:** D1 cathode toward the needle end (away from the cable holes), Q1 drain toward the needles, and U4 pin 1 at the corner nearest the board's center line and the cable end. D2 is bidirectional.

Correct any rotation there before paying.

## Advanced assembly options

| Option | Selection |
| --- | --- |
| Bake Components | No optional blanket bake; normal required moisture handling still applies |
| Board Cleaning | **No** |
| Special stencil | No (standard stencils for both faces) |
| Depanel boards & edge rail before delivery | **Yes** |
| Flying Probe Test | No optional assembled-board service; keep the bare-board electrical test |
| Function test | No; no programmed functional-test package is supplied |
| Photo Confirmation | No |
| Conformal Coating | No |
| Packaging | Antistatic bubble film, with rigid prong protection requested below |
| Solder Paste | High temp., lead-free, compatible rosin no-clean flux |
| Nitrogen reflow | No |
| Assembly remark | Yes; use the paragraph below |

## Assembly remark

Copy only this paragraph; it is shorter than 500 characters:

> HP-HAT: exact BOM/CPL; RH1-RH17=C313752, 0.33W only. Two-sided assembly. J1/J3/J4: leave holes empty. Custom support panel; preserve outline, 4 layers, 0.8 mm. Deliver depanelized; remove tabs flush from 1.4 mm prongs without damaging copper, mask or parts. No markings on prongs. Lead-free HASL/solder, rosin no-clean flux. DO NOT CLEAN: Murata NCP15 thermistors. No solvent, dry ice, ultrasonics or coating. Rigid packing to protect prongs.

## Cleaning and later assembly

Keep **Board Cleaning: No**. The [Murata NCP15 specification](https://www.murata.com/-/media/webrenewal/products/thermistor/ntc/ncp/ncp15.ashx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) excludes cleaning after no-clean flux. Use compatible rosin-based no-clean flux and do not wash, spray or immerse the assembled sensor. Do not select solvent, dry-ice or ultrasonic whole-board cleaning.

Use the exact 17 × 3.3 ohm Vishay CRCW06033R30FKEAHP 0.33 W heater resistors (C313752), the same as flat-nano; do not substitute a lower-power part. Keep the exact Murata NTCs, 0.1% reference resistors, current shunt and INA226.

After delivery, solder the two boards and three field wires, inspect all joints, and bench-test through USB and the intended battery/logger supply before potting. Use flat, separated wire terminations on the hat's outer face between the cable end and the cable holes, as described in the assembly guide; do not stack insulated wires under the board. Insulate copper from steel needles. Choose potting compatible with no-clean residues and thermistors, and compare readings before and after the first cure. Solder mask is not a waterproof enclosure.

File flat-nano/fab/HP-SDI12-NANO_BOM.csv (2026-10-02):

Comment | Designator | Footprint | LCSC Part # | Manufacturer Part Number | Qty | Description
10u 50V | C1,C17 | C_0805_2012Metric | C440198 | GRM21BR61H106KE43L | 2 | MLCC 10 uF 50 V X5R 0805 (VIN input C1 and +5 V output C17)
22u 25V | C2,C3 | C_1206_3216Metric | C12891 | CL31A226KAHNNNE | 2 | MLCC 22 uF 25 V X5R 1206 (bulk input capacitor C3 and buck output capacitor C2)
3.3n | C4 | C_0402_1005Metric | C26404 | CL05B332KB5NNNC | 1 | MLCC 3.3 nF 50 V X7R 0402
100n | C7,C8,C9,C11,C12,C18,C19,C21,C22,C23,C24 | C_0402_1005Metric | C307331 | CL05B104KB54PNC | 11 | MLCC 100 nF 50 V X7R 0402
4.7u | C10,C16 | C_0603_1608Metric | C19666 | CL10A475KO8NNNC | 2 | MLCC 4.7 uF 16 V X5R 0603
1u | C13,C20 | C_0402_1005Metric | C52923 | CL05A105KA5NQNC | 2 | MLCC 1 uF 25 V X5R 0402
1A 40V Schottky (SOD-323) | D1,D5,D7 | D_SOD-323 | C191023 | 1N5819WS | 3 | Schottky 1 A 40 V, SOD-323
SMF16CA 16V bidir TVS | D2 | D_SOD-123F | C19077511 | SMF16CA | 1 | TVS 16 V standoff, bidirectional, SOD-123FL (clamp about 26 V)
bidir ESD diode 6-7V (SOD-323) | D4 | D_SOD-323 | C19224 | PESD5V0S1BA,115 | 1 | ESD diode bidirectional 5 V, SOD-323
22uH | L1 | L_Sunlord_SWPA4020S | C82401 | SWPA4020S220MT | 1 | Power inductor 22 uH 20 %, 0.62 A saturation, 4x4 mm (buck)
AO3400A | Q1 | SOT-23 | C20917 | AO3400A | 1 | N-MOSFET 30 V logic level, SOT-23
10k | R1,R2,R16 | R_0402_1005Metric | C25744 | 0402WGF1002TCE | 3 | Resistor 10 k 1 % 0402
1.5k 1% | R3 | R_0603_1608Metric | C22843 | 0603WAF1501T5E | 1 | Resistor 1.5 k 1 % 0603 (SDI-12 transmit resistance)
220k | R4 | R_0402_1005Metric | C25767 | 0402WGF2203TCE | 1 | Resistor 220 k 1 % 0402
0.1 1% | R5 | R_0805_2012Metric | C2094615 | WSL0805R1000FEA | 1 | Current-sense resistor 0.1 ohm 1 %, 0805 - no substitutes
4.7k | R6,R7 | R_0402_1005Metric | C25900 | 0402WGF4701TCE | 2 | Resistor 4.7 k 1 % 0402
1.5k | R9,R11 | R_0402_1005Metric | C25867 | 0402WGF1501TCE | 2 | Resistor 1.5 k ohm 1%, 0402 (R9 gate drive, R11 thermistor excitation)
100k | R10 | R_0402_1005Metric | C25741 | 0402WGF1003TCE | 1 | Resistor 100 k 1 % 0402
5.1k | R14,R15 | R_0402_1005Metric | C25905 | 0402WGF5101TCE | 2 | Resistor 5.1 k 1 % 0402
10k 0.1% | R21,R22,R23,R24 | R_0603_1608Metric | C54973934 | CRF0603Q103BN | 4 | Resistor 10 k 0.1 % 25 ppm, 0603 - no substitutes
3.3 | RH1,RH2,RH3,RH4,RH5,RH6,RH7,RH8,RH9,RH10,RH11,RH12,RH13,RH14,RH15,RH16,RH17 | R_0603_Vishay_HP | C313752 | CRCW06033R30FKEAHP | 17 | HEATER: Vishay high-power 0603 3.3 ohm 1%, 0.33 W at 70 C, derates above 70 C. Exact CRCW-HP part required; no ordinary 0.1 W/0.125 W substitutes
10k NTC 1% | TH1,TH2,TH3,TH4 | R_0402_1005Metric | C77131 | NCP15XH103F03RC | 4 | NTC thermistor 10 k 1 % B3380, 0402 - no substitutes
R7FA4M1AB3CFM | U1 | LQFP-64_10x10mm_P0.5mm | C1340737 | R7FA4M1AB3CFM#AA0 | 1 | Renesas RA4M1 MCU, LQFP-64
LMR36503R5RPER | U3 | TI_RPE0009A_VQFN-HR-9_2x2mm | C3190197 | LMR36503R5RPER | 1 | TI 5 V synchronous buck, 3-65 V in, 300 mA, VQFN-HR-9 2x2 mm
INA226 | U4 | MSOP-10_3x3mm_P0.5mm | C49851 | INA226AIDGSR | 1 | TI INA226 power monitor, VSSOP-10

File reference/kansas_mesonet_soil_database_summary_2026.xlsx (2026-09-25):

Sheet: references
Reference | Comment
Parker, N. (2021). Development and applications of a new database of soil physical properties for the Kansas Mesonet. Kansas State University. https://er.lib.k-state.edu/login | Dissertation with the most complete level of detail. Note that peer-reviewed articles have the most up-to-date information | This source has more details than the articles below.
Parker, N., Kluitenberg, G. J., Redmond, C., & Patrignani, A. (2022). A database of soil physical properties for the Kansas Mesonet. Soil Science Society of America Journal, 86(6), 1495-1508. https://doi.org/10.1002/saj2.20465 | Description of sampling methods, general, and hydraulic properties | Recommended citation for most peer-reiewed articles.
Patrignani, A., Ghanbarian, B., Kluitenberg, G. J., & Parker, N. (2023). Validation of the percolation‐based effective‐medium approximation model to estimate soil thermal conductivity. Soil Science Society of America Journal, 87(6), 1275-1284. https://doi.org/10.1002/saj2.20585 | Study that used 38 soils of this database with measurements of thermal properties at multiple thermal properties. This study did not use all the available thermal property data. | Short sutdy using a selected number of samples with soil thermal properties only.

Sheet: general_properties
station_name | county | latitude | longitude | ring_number | core_number | top_depth | bottom_depth | nominal_depth | sampling_date | sampling_time | sand | clay | silt | textural_class | bulk_density | particle_density | porosity | L_dry | a_dry | b_dry | L_wet | a_wet | b_wet | total_N | total_C | Ca | Mg | Na | OM | P | pH | pH_buffer | K_ppm
Manhattan | Riley | 39.20856 | -96.59169 | 1 | 1 | 3 | 8 | 5 | 2018-06-27 | 9:00:00 |  |  |  | silty clay loam | 1.402 | 2.619 | 0.465 |  |  |  |  |  |  | 0.18 | 1.8 | 2362.2 | 357.8 | 122.1 | 3.3 | 33 | 5.9 | 6.4 | 326.5
Manhattan | Riley | 39.20856 | -96.59169 | 2 | 1 | 9 | 14 | 10 | 2018-06-27 | 9:00:00 |  |  |  | silty clay loam | 1.482 | 2.635 | 0.438 |  |  |  |  |  |  | 0.14 | 1.45 | 2446.1 | 390.4 | 159.5 | 2.8 | 10.1 | 6.3 | 6.5 | 208.7
Manhattan | Riley | 39.20856 | -96.59169 | 3 | 1 | 18 | 23 | 20 | 2018-06-27 | 9:00:00 |  |  |  | silty clay loam | 1.376 | 2.687 | 0.488 |  |  |  |  |  |  | 0.14 | 1.4 | 2575.7 | 401.8 | 173 | 2.9 | 7.4 | 6.1 | 6.5 | 168.6
Manhattan | Riley | 39.20856 | -96.59169 | 4 | 1 | 47 | 52 | 50 | 2018-06-27 | 9:00:00 |  |  |  | silty clay loam | 1.506 | 2.676 | 0.437 |  |  |  |  |  |  | 0.1 | 0.87 | 3334.6 | 668.7 | 203.7 | 2.3 | 1.6 | 6.7 | 6.7 | 258.1
Manhattan | Riley | 39.20856 | -96.59169 | 5 | 2 | 2 | 7 | 5 | 2018-06-27 | 9:00:00 | 10.9 | 29.3 | 59.8 | silty clay loam | 1.306 | 2.786 | 0.531 | 40.8 | 7.3 | 13.3 | 23.6 | 5.4 | 10.1
Manhattan | Riley | 39.20856 | -96.59169 | 6 | 2 | 11 | 16 | 10 | 2018-06-27 | 9:00:00 | 8.6 | 33.2 | 58.2 | silty clay loam | 1.363 | 2.613 | 0.479 | 44.5 | 6.1 | 11.7 | 25.6 | 4 | 7.9
Manhattan | Riley | 39.20856 | -96.59169 | 7 | 2 | 20 | 25 | 20 | 2018-06-27 | 9:00:00 | 8.7 | 33.2 | 58.1 | silty clay loam | 1.390 | 2.593 | 0.464 | 42.9 | 6.1 | 12.1 | 22.3 | 4.8 | 7.1
Manhattan | Riley | 39.20856 | -96.59169 | 8 | 2 | 50 | 55 | 50 | 2018-06-27 | 9:00:00 | 5.5 | 38.6 | 55.9 | silty clay loam | 1.470 | 2.632 | 0.442 | 46.6 | 6.2 | 13 | 25.6 | 5.1 | 8.6
Ashland Bottoms | Riley | 39.12584 | -96.63643 | 9 | 1 | 2 | 7 | 5 | 2018-06-27 | 12:00:00 |  |  |  | silty clay loam | 1.436 | 2.592 | 0.446 |  |  |  |  |  |  | 0.17 | 1.63 | 2584.6 | 365.7 | 118.3 | 3.2 | 5.4 | 6.1 | 6.6 | 340.7
Ashland Bottoms | Riley | 39.12584 | -96.63643 | 10 | 1 | 8 | 13 | 10 | 2018-06-27 | 12:00:00 |  |  |  | silty clay loam | 1.352 | 2.631 | 0.486 |  |  |  |  |  |  | 0.12 | 1.22 | 2690.6 | 410.3 | 111.8 | 2.7 | 3.2 | 6.2 | 6.6 | 209.2
Ashland Bottoms | Riley | 39.12584 | -96.63643 | 11 | 1 | 17 | 22 | 20 | 2018-06-27 | 12:00:00 |  |  |  | silty clay | 1.239 | 2.636 | 0.530 |  |  |  |  |  |  | 0.12 | 1.1 | 3166 | 556.8 | 119.8 | 2.6 | 2.1 | 6 | 6.5 | 231.3
Ashland Bottoms | Riley | 39.12584 | -96.63643 | 12 | 1 | 49 | 54 | 50 | 2018-06-27 | 12:00:00 |  |  |  | silty clay | 1.184 | 2.608 | 0.546 |  |  |  |  |  |  | 0.08 | 0.87 | 3465 | 676.4 | 168.7 | 2.2 | 1 | 6.8 | 6.8 | 255.5
Ashland Bottoms | Riley | 39.12584 | -96.63643 | 13 | 2 | 1 | 6 | 5 | 2018-06-27 | 12:00:00 | 8.6 | 33.2 | 58.2 | silty clay loam | 1.286 | 2.541 | 0.494 | 41 | 5.8 | 12.3 | 26 | 5.4 | 9.7
Ashland Bottoms | Riley | 39.12584 | -96.63643 | 14 | 2 | 8 | 13 | 10 | 2018-06-27 | 12:00:00 | 5.0 | 37.2 | 57.8 | silty clay loam | 1.341 | 2.527 | 0.469 | 28.9 | 5.5 | 9.3 | 26.2 | 5.3 | 8.5
Ashland Bottoms | Riley | 39.12584 | -96.63643 | 15 | 2 | 16 | 21 | 20 | 2018-06-27 | 12:00:00 | 2.6 | 50.7 | 46.8 | silty clay | 1.285 | 2.537 | 0.493 | 41.1 | 6.5 | 11.8 | 28.9 | 6.4 | 10.7
Ashland Bottoms | Riley | 39.12584 | -96.63643 | 16 | 2 | 47 | 52 | 50 | 2018-06-27 | 12:00:00 | 2.8 | 44.1 | 53.1 | silty clay | 1.345 | 2.676 | 0.497 | 43.1 | 6.5 | 13.9 | 29.8 | 6.2 | 11.8
Clay Center | Clay | 39.41722 | -97.13926 | 17 | 1 | 1 | 6 | 5 | 2018-06-27 | 14:00:00 |  |  |  | silty clay | 1.269 | 2.538 | 0.500 |  |  |  |  |  |  | 0.26 | 2.67 | 2037.2 | 266.6 | 103.1 | 4.8 | 16.1 | 6 | 6.7 | 506.2
Clay Center | Clay | 39.41722 | -97.13926 | 18 | 1 | 8 | 13 | 10 | 2018-06-27 | 14:00:00 |  |  |  | silt loam | 1.356 | 2.525 | 0.463 |  |  |  |  |  |  | 0.17 | 1.76 | 1986.9 | 259 | 107.4 | 3.2 | 5.9 | 6.2 | 6.7 | 385
Clay Center | Clay | 39.41722 | -97.13926 | 19 | 1 | 16 | 21 | 20 | 2018-06-27 | 14:00:00 |  |  |  | silt loam | 1.302 | 2.563 | 0.492 |  |  |  |  |  |  | 0.15 | 1.59 | 2169.2 | 361.7 | 104.1 | 3 | 2.9 | 6.2 | 6.7 | 269.4
Clay Center | Clay | 39.41722 | -97.13926 | 20 | 1 | 50 | 55 | 50 | 2018-06-27 | 14:00:00 |  |  |  | silty clay loam | 1.225 | 2.663 | 0.540 |  |  |  |  |  |  | 0.1 | 0.86 | 2874.1 | 569.4 | 146.3 | 2.2 | 1.2 | 6.9 | 7 | 279
Clay Center | Clay | 39.41722 | -97.13926 | 21 | 2 | 2 | 7 | 5 | 2018-06-27 | 14:00:00 | 11.8 | 43.1 | 45.0 | silty clay | 1.339 | 2.516 | 0.468 | 44.1 | 6.7 | 12 | 22.2 | 4.7 | 7.6
Clay Center | Clay | 39.41722 | -97.13926 | 22 | 2 | 9 | 14 | 10 | 2018-06-27 | 14:00:00 | 9.2 | 25.4 | 65.4 | silt loam | 1.423 | 2.625 | 0.458 | 44.9 | 6.3 | 11.8 | 26.2 | 5.5 | 8.9
Clay Center | Clay | 39.41722 | -97.13926 | 23 | 2 | 17 | 22 | 20 | 2018-06-27 | 14:00:00 | 9.1 | 26.7 | 64.2 | silt loam | 1.341 | 2.542 | 0.472 | 43.8 | 6.9 | 12.9 | 24.7 | 5.6 | 8.7
Clay Center | Clay | 39.41722 | -97.13926 | 24 | 2 | 49 | 54 | 50 | 2018-06-27 | 14:00:00 | 5.5 | 36.0 | 58.5 | silty clay loam | 1.215 | 2.567 | 0.527 | 48.3 | 7.1 | 14.5 | 28.9 | 6.2 | 11
Washington | Washington | 39.7812 | -97.05978 | 25 | 1 | 2 | 7 | 5 | 2018-07-20 | 8:00:00 |  |  |  | clay loam | 1.408 | 2.619 | 0.462 |  |  |  |  |  |  | 0.12 | 1.75 | 1952.8 | 419.8 | 55.5 | 3.3 | 2 | 5.6 | 6.4 | 180
Washington | Washington | 39.7812 | -97.05978 | 26 | 1 | 8 | 13 | 10 | 2018-07-20 | 8:00:00 |  |  |  | clay loam | 1.440 | 2.597 | 0.445 |  |  |  |  |  |  | 0.11 | 1.27 | 1937.3 | 405.5 | 57 | 2.8 | 1 | 5.4 | 6.4 | 141.6
Washington | Washington | 39.7812 | -97.05978 | 27 | 1 | 18 | 23 | 20 | 2018-07-20 | 8:00:00 |  |  |  | clay loam | 1.351 | 2.501 | 0.460 |  |  |  |  |  |  | 0.09 | 1 | 2213 | 469.4 | 79.7 | 2.4 | 0.6 | 6 | 6.6 | 153.1
Washington | Washington | 39.7812 | -97.05978 | 28 | 1 | 49 | 54 | 50 | 2018-07-20 | 8:00:00 |  |  |  | clay loam | 1.458 | 2.632 | 0.446 |  |  |  |  |  |  | 0.06 | 0.51 | 2585.1 | 586.1 | 116 | 1.5 | 0.4 | 6.3 | 6.8 | 180.9
Washington | Washington | 39.7812 | -97.05978 | 29 | 2 | 2 | 7 | 5 | 2018-07-20 | 8:00:00 | 24.1 | 30.6 | 45.3 | clay loam | 1.352 | 2.466 | 0.452 | 45.8 | 8.3 | 16.1 | 25.8 | 8.5 | 12.7
Washington | Washington | 39.7812 | -97.05978 | 30 | 2 | 8 | 13 | 10 | 2018-07-20 | 8:00:00 | 25.3 | 29.4 | 45.3 | clay loam | 1.448 | 2.638 | 0.451 | 51.4 | 11.5 | 20 | 29.9 | 9 | 14.4
Washington | Washington | 39.7812 | -97.05978 | 31 | 2 | 19 | 24 | 20 | 2018-07-20 | 8:00:00 | 21.2 | 34.6 | 44.2 | clay loam | 1.386 | 2.675 | 0.482 | 45.4 | 10.3 | 18.3 | 30.2 | 10.6 | 14.3
Washington | Washington | 39.7812 | -97.05978 | 32 | 2 | 51 | 56 | 50 | 2018-07-20 | 8:00:00 | 20.9 | 36.0 | 43.1 | clay loam | 1.440 | 2.667 | 0.460 | 51.1 | 10.6 | 17.9 | 33.7 | 10.2 | 15.4
Belleville 2W | Republic | 39.814 | -97.6751 | 33 | 1 | 2 | 7 | 5 | 2018-07-20 | 11:00:00 |  |  |  | silt loam | 1.215 | 2.408 | 0.495 |  |  |  |  |  |  | 0.26 | 2.76 | 2376 | 234.6 | 216.2 | 4.7 | 148 | 6.1 | 6.7 | 782.4
Belleville 2W | Republic | 39.814 | -97.6751 | 34 | 1 | 8 | 13 | 10 | 2018-07-20 | 11:00:00 |  |  |  | silty clay loam | 1.264 | 2.536 | 0.502 |  |  |  |  |  |  | 0.2 | 2.03 | 2192.6 | 244.6 | 212.5 | 3.6 | 216 | 5.8 | 6.4 | 782.5
Belleville 2W | Republic | 39.814 | -97.6751 | 35 | 1 | 19 | 24 | 20 | 2018-07-20 | 11:00:00 |  |  |  | silty clay loam | 1.140 | 2.496 | 0.543 |  |  |  |  |  |  | 0.16 | 1.84 | 2722.8 | 336.3 | 206.4 | 3.3 | 325 | 6.7 | 6.9 | 1158.6
Belleville 2W | Republic | 39.814 | -97.6751 | 36 | 1 | 48 | 53 | 50 | 2018-07-20 | 11:00:00 |  |  |  | silty clay | 1.093 | 2.597 | 0.579 |  |  |  |  |  |  | 0.12 | 1.25 | 3023.9 | 452.7 | 397.1 | 2.7 | 165 | 7.5 | 7.2 | 2262.3
Belleville 2W | Republic | 39.814 | -97.6751 | 37 | 2 | 1 | 6 | 5 | 2018-07-20 | 11:00:00 | 11.7 | 21.6 | 66.7 | silt loam | 1.122 | 2.500 | 0.551 | 43.4 | 5 | 8.9 | 22.4 | 4.1 | 6.2
Belleville 2W | Republic | 39.814 | -97.6751 | 38 | 2 | 7 | 12 | 10 | 2018-07-20 | 11:00:00 | 11.0 | 28.0 | 61.1 | silty clay loam | 1.243 | 2.619 | 0.525 | 39.3 | 4.2 | 7.9 | 17.9 | 2.9 | 4.5
Belleville 2W | Republic | 39.814 | -97.6751 | 39 | 2 | 19 | 24 | 20 | 2018-07-20 | 11:00:00 | 10.3 | 29.3 | 60.4 | silty clay loam | 1.228 | 2.575 | 0.523 | 41.9 | 4.1 | 8.4 | 21.4 | 3.5 | 5.4
Belleville 2W | Republic | 39.814 | -97.6751 | 40 | 2 | 50 | 55 | 50 | 2018-07-20 | 11:00:00 | 7.1 | 44.8 | 48.1 | silty clay | 1.077 | 2.619 | 0.589 | 41 | 4.7 | 9.3 | 18.8 | 3.4 | 5.2
Osborne | Osborne | 39.45441 | -98.70357 | 41 | 1 | 2 | 7 | 5 | 2018-07-20 | 14:00:00 |  |  |  | silt loam | 1.189 | 2.501 | 0.525 |  |  |  |  |  |  | 0.2 | 2.07 | 2221.1 | 242.3 | 217.1 | 3.6 | 18.1 | 5.8 | 6.5 | 412.1
Osborne | Osborne | 39.45441 | -98.70357 | 42 | 1 | 8 | 13 | 10 | 2018-07-20 | 14:00:00 |  |  |  | silty clay loam | 1.284 | 2.617 | 0.510 |  |  |  |  |  |  | 0.14 | 1.44 | 2975 | 345.8 | 221.7 | 3 | 9.5 | 6.4 | 6.8 | 272.2
Osborne | Osborne | 39.45441 | -98.70357 | 43 | 1 | 19 | 24 | 20 | 2018-07-20 | 14:00:00 |  |  |  | silty clay loam | 1.314 | 2.699 | 0.513 |  |  |  |  |  |  | 0.11 | 1.21 | 3713.1 | 485.8 | 204.6 | 2.6 | 7.3 | 6.6 | 6.9 | 337.2
Osborne | Osborne | 39.45441 | -98.70357 | 44 | 1 | 49 | 54 | 50 | 2018-07-20 | 14:00:00 |  |  |  | silty clay loam | 1.236 | 2.629 | 0.530 |  |  |  |  |  |  | 0.08 | 0.65 | 3873.5 | 536 | 218.9 | 1.8 | 21.9 | 7.5 | 7.3 | 373.4
Osborne | Osborne | 39.45441 | -98.70357 | 45 | 2 | 2 | 7 | 5 | 2018-07-20 | 14:00:00 | 13.6 | 24.1 | 62.2 | silt loam | 1.092 | 2.676 | 0.592 | 50.8 | 7 | 13.2 | 27.2 | 4.7 | 7.6
Osborne | Osborne | 39.45441 | -98.70357 | 46 | 2 | 9 | 14 | 10 | 2018-07-20 | 14:00:00 | 11.1 | 32.0 | 56.9 | silty clay loam | 1.064 | 2.541 | 0.581 | 46.3 | 6 | 11.3 | 25.5 | 4.6 | 7.3
Osborne | Osborne | 39.45441 | -98.70357 | 47 | 2 | 17 | 22 | 20 | 2018-07-20 | 14:00:00 | 8.3 | 35.9 | 55.8 | silty clay loam | 1.055 | 2.558 | 0.588 | 46.7 | 5.7 | 11.8 | 27.2 | 4.4 | 8.1
Osborne | Osborne | 39.45441 | -98.70357 | 48 | 2 | 48 | 53 | 50 | 2018-07-20 | 14:00:00 | 8.3 | 35.9 | 55.8 | silty clay loam | 1.162 | 2.543 | 0.543 | 58.7 | 6.7 | 15.2 | 31 | 6.3 | 12
Mitchell | Mitchell | 39.43725 | -98.21011 | 49 | 1 | 2 | 7 | 5 | 2018-07-20 | 16:00:00 |  |  |  | silty clay loam | 1.129 | 2.570 | 0.561 |  |  |  |  |  |  | 0.21 | 2.34 | 3609.7 | 210.9 | 150.7 | 4.2 | 23 | 6.9 | 7.1 | 577.7
Mitchell | Mitchell | 39.43725 | -98.21011 | 50 | 1 | 8 | 13 | 10 | 2018-07-20 | 16:00:00 |  |  |  | silty clay loam | 1.140 | 2.520 | 0.548 |  |  |  |  |  |  | 0.16 | 1.71 | 3755.2 | 200.2 | 188.9 | 3.3 | 19.6 | 7.4 | 7.2 | 481.2
Mitchell | Mitchell | 39.43725 | -98.21011 | 51 | 1 | 17 | 22 | 20 | 2018-07-20 | 16:00:00 |  |  |  | silty clay loam | 1.151 | 2.536 | 0.546 |  |  |  |  |  |  | 0.14 | 1.54 | 3973.2 | 226.6 | 177.8 | 3.3 | 11.4 | 7.2 | 7.1 | 380.5
Mitchell | Mitchell | 39.43725 | -98.21011 | 52 | 1 | 50 | 55 | 50 | 2018-07-20 | 16:00:00 |  |  |  | silty clay loam | 1.140 | 2.555 | 0.554 |  |  |  |  |  |  | 0.08 | 0.84 | 4263.9 | 432.7 | 261.4 | 2.1 | 10.1 | 7.4 | 7.2 | 349.7
Mitchell | Mitchell | 39.43725 | -98.21011 | 53 | 2 | 1 | 6 | 5 | 2018-07-20 | 16:00:00 | 8.0 | 39.9 | 52.1 | silty clay loam | 1.005 | 2.464 | 0.592 | 44.3 | 6 | 10.2 | 24.4 | 4.4 | 6.8
Mitchell | Mitchell | 39.43725 | -98.21011 | 54 | 2 | 8 | 13 | 10 | 2018-07-20 | 16:00:00 | 9.6 | 28.0 | 62.4 | silty clay loam | 1.335 | 2.602 | 0.487 | 49.3 | 6.1 | 11.3 | 22.3 | 3.6 | 6.9
Mitchell | Mitchell | 39.43725 | -98.21011 | 55 | 2 | 19 | 24 | 20 | 2018-07-20 | 16:00:00 | 6.2 | 29.4 | 64.5 | silty clay loam | 1.168 | 2.542 | 0.540 | 47.9 | 6.1 | 11.9 | 29.6 | 4.7 | 8.8
Mitchell | Mitchell | 39.43725 | -98.21011 | 56 | 2 | 49 | 54 | 50 | 2018-07-20 | 16:00:00 | 4.0 | 35.9 | 60.2 | silty clay loam | 1.189 | 2.682 | 0.557 | 52.6 | 7 | 14.1 | 36.2 | 6.9 | 13.1
Gypsum | Saline | 38.72509 | -97.44423 | 57 | 1 | 2 | 7 | 5 | 2018-07-23 | 9:00:00 |  |  |  | silty clay loam | 1.422 | 2.667 | 0.467 |  |  |  |  |  |  | 0.12 | 1.34 | 2122.6 | 583 | 36.7 | 2.5 | 15.9 | 6.3 | 6.7 | 404.5
Gypsum | Saline | 38.72509 | -97.44423 | 58 | 1 | 8 | 13 | 10 | 2018-07-23 | 9:00:00 |  |  |  | silty clay loam | 1.404 | 2.656 | 0.471 |  |  |  |  |  |  | 0.13 | 1.58 | 2411.5 | 606.5 | 40.3 | 3 | 24.1 | 6.8 | 6.9 | 236.8
Gypsum | Saline | 38.72509 | -97.44423 | 59 | 1 | 16 | 21 | 20 | 2018-07-23 | 9:00:00 |  |  |  | silty clay loam | 1.289 | 2.606 | 0.505 |  |  |  |  |  |  | 0.12 | 1.37 | 2285.8 | 561 | 33.1 | 2.6 | 26.6 | 6.2 | 6.8 | 224.6
Gypsum | Saline | 38.72509 | -97.44423 | 60 | 1 | 53 | 58 | 50 | 2018-07-23 | 9:00:00 |  |  |  | silty clay loam | 1.218 | 2.638 | 0.538 |  |  |  |  |  |  | 0.11 | 1.48 | 2396.1 | 649.1 | 54.8 | 2.8 | 15.6 | 6.6 | 6.8 | 171.9
Gypsum | Saline | 38.72509 | -97.44423 | 61 | 2 | 2 | 7 | 5 | 2018-07-23 | 9:00:00 | 5.3 | 31.8 | 63.0 | silty clay loam | 1.356 | 2.550 | 0.468 | 42 | 5.7 | 10.6 | 23.5 | 4.6 | 7.2
Gypsum | Saline | 38.72509 | -97.44423 | 62 | 2 | 8 | 13 | 10 | 2018-07-23 | 9:00:00 | 8.5 | 29.2 | 62.2 | silty clay loam | 1.481 | 2.621 | 0.435 | 45.2 | 5.5 | 11.8 | 24.7 | 4.5 | 6.8
Gypsum | Saline | 38.72509 | -97.44423 | 63 | 2 | 16 | 21 | 20 | 2018-07-23 | 9:00:00 | 7.9 | 27.9 | 64.1 | silty clay loam | 1.421 | 2.602 | 0.454 | 38.8 | 5.7 | 10.6 | 22.2 | 4 | 6.7
Gypsum | Saline | 38.72509 | -97.44423 | 64 | 2 | 50 | 55 | 50 | 2018-07-23 | 9:00:00 | 8.5 | 30.5 | 61.0 | silty clay loam | 1.393 | 2.631 | 0.470 | 41.8 | 6.5 | 11.4 | 25.3 | 4.7 | 7.5
McPherson 1S | McPherson | 38.34498 | -97.66317 | 65 | 1 | 2 | 7 | 5 | 2018-07-23 | 12:00:00 |  |  |  | silty clay loam | 1.461 | 2.689 | 0.457 |  |  |  |  |  |  | 0.12 | 1.25 | 2299.5 | 575.1 | 57.5 | 2.5 | 16.3 | 5.3 | 6.1 | 290.2
McPherson 1S | McPherson | 38.34498 | -97.66317 | 66 | 1 | 9 | 14 | 10 | 2018-07-23 | 12:00:00 |  |  |  | silty clay loam | 1.442 | 2.630 | 0.452 |  |  |  |  |  |  | 0.1 | 1.16 | 2172.4 | 534 | 56.2 | 2.2 | 9 | 5.4 | 6.2 | 209.1
McPherson 1S | McPherson | 38.34498 | -97.66317 | 67 | 1 | 16 | 21 | 20 | 2018-07-23 | 12:00:00 |  |  |  | silty clay | 1.394 | 2.623 | 0.469 |  |  |  |  |  |  | 0.1 | 1.05 | 3225 | 820.9 | 86.5 | 2.1 | 2.9 | 6.4 | 6.6 | 281.6
McPherson 1S | McPherson | 38.34498 | -97.66317 | 68 | 1 | 48 | 53 | 50 | 2018-07-23 | 12:00:00 |  |  |  | silty clay | 1.462 | 2.684 | 0.455 |  |  |  |  |  |  | 0.05 | 0.53 | 3846.6 | 1079.3 | 205.8 | 1.5 | 6.1 | 7.4 | 7.1 | 320.3
McPherson 1S | McPherson | 38.34498 | -97.66317 | 69 | 2 | 2 | 7 | 5 | 2018-07-23 | 12:00:00 | 3.0 | 33.4 | 63.6 | silty clay loam | 1.384 | 2.630 | 0.474 | 45.8 | 6.4 | 11.6 | 26 | 5.2 | 7.8
McPherson 1S | McPherson | 38.34498 | -97.66317 | 70 | 2 | 10 | 15 | 10 | 2018-07-23 | 12:00:00 | 5.3 | 36.1 | 58.6 | silty clay loam | 1.374 | 2.693 | 0.490 | 48.5 | 6.5 | 12 | 30 | 5.8 | 9
McPherson 1S | McPherson | 38.34498 | -97.66317 | 71 | 2 | 15 | 20 | 20 | 2018-07-23 | 12:00:00 | 3.7 | 44.2 | 52.0 | silty clay | 1.389 | 2.567 | 0.459 | 49.9 | 6.4 | 12.4 | 27.8 | 5.3 | 8.9
McPherson 1S | McPherson | 38.34498 | -97.66317 | 72 | 2 | 50 | 55 | 50 | 2018-07-23 | 12:00:00 | 2.1 | 45.7 | 52.2 | silty clay | 1.448 | 2.703 | 0.464 | 54.1 | 6.4 | 13.5 | 30.1 | 6.3 | 10.8
Lorraine | Ellsworth | 38.55793 | -98.3522 | 73 | 1 | 1 | 6 | 5 | 2018-07-23 | 14:00:00 |  |  |  | silty clay loam | 1.260 | 2.627 | 0.520 |  |  |  |  |  |  | 0.16 | 2.07 | 2663.9 | 442.4 | 26.6 | 3.3 | 42.2 | 6.6 | 6.9 | 572.9
Lorraine | Ellsworth | 38.55793 | -98.3522 | 74 | 1 | 8 | 13 | 10 | 2018-07-23 | 14:00:00 |  |  |  | silty clay | 1.401 | 2.643 | 0.470 |  |  |  |  |  |  | 0.13 | 1.71 | 2739 | 498.7 | 29 | 2.7 | 13.5 | 6.4 | 6.7 | 423.4
Lorraine | Ellsworth | 38.55793 | -98.3522 | 75 | 1 | 17 | 22 | 20 | 2018-07-23 | 14:00:00 |  |  |  | silty clay loam | 1.547 | 2.670 | 0.420 |  |  |  |  |  |  | 0.11 | 1.33 | 2905.1 | 572.2 | 39.6 | 2.3 | 4.4 | 6.4 | 6.7 | 257.8
Lorraine | Ellsworth | 38.55793 | -98.3522 | 76 | 1 | 51 | 56 | 50 | 2018-07-23 | 14:00:00 |  |  |  | silty clay loam | 1.550 | 2.684 | 0.423 |  |  |  |  |  |  | 0.07 | 0.73 | 3941.2 | 791.5 | 101.3 | 1.9 | 0.8 | 7 | 7 | 326.3
Lorraine | Ellsworth | 38.55793 | -98.3522 | 77 | 2 | 2 | 7 | 5 | 2018-07-23 | 14:00:00 | 10.9 | 29.3 | 59.8 | silty clay loam | 1.354 | 2.613 | 0.482 | 45 | 6.9 | 11.5 | 23.7 | 5.1 | 7.1
Lorraine | Ellsworth | 38.55793 | -98.3522 | 78 | 2 | 8 | 13 | 10 | 2018-07-23 | 14:00:00 | 9.7 | 46.4 | 43.8 | silty clay | 1.469 | 2.661 | 0.448 | 54.2 | 6.7 | 13.6 | 29 | 5.5 | 9.9
Lorraine | Ellsworth | 38.55793 | -98.3522 | 79 | 2 | 16 | 21 | 20 | 2018-07-23 | 14:00:00 | 6.6 | 38.4 | 55.0 | silty clay loam | 1.448 | 2.665 | 0.457 | 44.7 | 5.8 | 10.9 | 23.8 | 4.5 | 7.9
Lorraine | Ellsworth | 38.55793 | -98.3522 | 80 | 2 | 48 | 53 | 50 | 2018-07-23 | 14:00:00 | 12.1 | 31.8 | 56.0 | silty clay loam | 1.547 | 2.731 | 0.434 | 46.6 | 6.8 | 12.4 | 26.3 | 5.6 | 8.2
Overbrook | Osage | 38.71658 | -95.51626 | 81 | 1 | 1 | 6 | 5 | 2018-09-26 | 10:00:00 |  |  |  | silty clay | 1.109 | 2.558 | 0.567 |  |  |  |  |  |  | 0.37 | 4.1 | 3832.4 | 772.2 | 35.9 | 7.4 | 7.8 | 6.2 | 6.5 | 363.4
Overbrook | Osage | 38.71658 | -95.51626 | 82 | 1 | 10 | 15 | 10 | 2018-09-26 | 10:00:00 |  |  |  | silty clay | 1.352 | 2.654 | 0.490 |  |  |  |  |  |  | 0.19 | 2.23 | 3911.2 | 881.3 | 38.6 | 4.3 | 3.9 | 6.6 | 6.7 | 252.3
Overbrook | Osage | 38.71658 | -95.51626 | 83 | 1 | 18 | 23 | 20 | 2018-09-26 | 10:00:00 |  |  |  | silty clay | 1.285 | 2.572 | 0.500 |  |  |  |  |  |  | 0.19 | 2.4 | 3919.7 | 1040.3 | 43.8 | 4.6 | 2.1 | 6.8 | 6.8 | 222
Overbrook | Osage | 38.71658 | -95.51626 | 84 | 1 | 45 | 50 | 50 | 2018-09-26 | 10:00:00 |  |  |  | clay | 1.427 | 2.715 | 0.474 |  |  |  |  |  |  | 0.07 | 0.71 | 3836.4 | 1466.1 | 74.1 | 2.4 | 0.4 | 7.5 | 7.1 | 202.3
Overbrook | Osage | 38.71658 | -95.51626 | 85 | 2 | 1 | 6 | 5 | 2018-09-26 | 10:00:00 | 5.6 | 39.8 | 54.6 | silty clay | 1.002 | 2.619 | 0.618 | 44 | 4.3 | 9.8 | 21.9 | 3.4 | 5.4
Overbrook | Osage | 38.71658 | -95.51626 | 86 | 2 | 8 | 13 | 10 | 2018-09-26 | 10:00:00 | 1.0 | 42.4 | 56.6 | silty clay | 1.199 | 2.624 | 0.543 | 36.3 | 4.3 | 8.6 | 20.7 | 2.9 | 4.9
Overbrook | Osage | 38.71658 | -95.51626 | 87 | 2 | 16 | 21 | 20 | 2018-09-26 | 10:00:00 | 3.4 | 41.2 | 55.4 | silty clay | 1.176 | 2.625 | 0.552 | 38.1 | 3.6 | 7.4 | 21.4 | 2.7 | 4.5
Overbrook | Osage | 38.71658 | -95.51626 | 88 | 2 | 47 | 52 | 50 | 2018-09-26 | 10:00:00 | 1.0 | 59.5 | 39.5 | clay | 1.338 | 2.672 | 0.499 | 55.4 | 5.6 | 18.7 | 36.2 | 5.7 | 16.4
Ottawa 2SE | Franklin | 38.54279 | -95.24662 | 89 | 1 | 2 | 7 | 5 | 2018-09-26 | 12:00:00 |  |  |  | silty clay loam | 1.215 | 2.538 | 0.521 |  |  |  |  |  |  | 0.25 | 2.76 | 2811.3 | 347.1 | 42.5 | 5 | 5.1 | 5.7 | 6.4 | 118.7
Ottawa 2SE | Franklin | 38.54279 | -95.24662 | 90 | 1 | 6 | 11 | 10 | 2018-09-26 | 12:00:00 |  |  |  | silty clay loam | 1.337 | 2.540 | 0.474 |  |  |  |  |  |  | 0.19 | 2.22 | 2819 | 332 | 53.9 | 4.1 | 2.4 | 5.9 | 6.5 | 92
Ottawa 2SE | Franklin | 38.54279 | -95.24662 | 91 | 1 | 10 | 15 | 20 | 2018-09-26 | 12:00:00 |  |  |  | silty clay loam | 1.338 | 2.450 | 0.454 |  |  |  |  |  |  | 0.16 | 1.95 | 2817 | 342.9 | 81.2 | 3.7 | 1.9 | 5.7 | 6.4 | 104.1
Ottawa 2SE | Franklin | 38.54279 | -95.24662 | 92 | 1 | 48 | 53 | 50 | 2018-09-26 | 12:00:00 |  |  |  | silty clay | 1.447 | 2.667 | 0.458 |  |  |  |  |  |  | 0.11 | 1.32 | 4174.5 | 743.4 | 266.3 | 3 | 0.8 | 6.4 | 6.5 | 234.2
Ottawa 2SE | Franklin | 38.54279 | -95.24662 | 93 | 2 | 1 | 6 | 5 | 2018-09-26 | 12:00:00 | 8.3 | 29.5 | 62.2 | silty clay loam | 1.165 | 2.542 | 0.541 | 45.5 | 5.1 | 9.7 | 23.3 | 3.3 | 6.9
Ottawa 2SE | Franklin | 38.54279 | -95.24662 | 94 | 2 | 8 | 13 | 10 | 2018-09-26 | 12:00:00 | 7.6 | 29.5 | 62.9 | silty clay loam | 1.351 | 2.555 | 0.471 | 46.9 | 5.5 | 9.7 | 24.8 | 4.3 | 7.1
Ottawa 2SE | Franklin | 38.54279 | -95.24662 | 95 | 2 | 16 | 21 | 20 | 2018-09-26 | 12:00:00 | 6.4 | 29.5 | 64.1 | silty clay loam | 1.268 | 2.602 | 0.513 | 45.1 | 4.9 | 8.5 | 19.6 | 3.1 | 5.1
Ottawa 2SE | Franklin | 38.54279 | -95.24662 | 96 | 2 | 47 | 52 | 50 | 2018-09-26 | 12:00:00 | 1.4 | 53.9 | 44.7 | silty clay | 1.305 | 2.606 | 0.499 | 41.2 | 3.3 | 8.2 | 21 | 3.5 | 5.5
Miami | Miami | 38.59214 | -94.84789 | 97 | 1 | 2 | 7 | 5 | 2018-09-26 | 14:00:00 |  |  |  | silty clay loam | 1.071 | 2.622 | 0.591 |  |  |  |  |  |  | 0.36 | 4.12 | 3261 | 359.1 | 39 | 7.4 | 1.7 | 5.6 | 6.3 | 131.5
Miami | Miami | 38.59214 | -94.84789 | 98 | 1 | 10 | 15 | 10 | 2018-09-26 | 14:00:00 |  |  |  | silty clay loam | 1.330 | 2.702 | 0.508 |  |  |  |  |  |  | 0.23 | 2.78 | 3017.1 | 366.1 | 41.3 | 5.3 | 0.6 | 5.9 | 6.4 | 121
Miami | Miami | 38.59214 | -94.84789 | 99 | 1 | 17 | 22 | 20 | 2018-09-26 | 14:00:00 |  |  |  | silty clay | 1.333 | 2.677 | 0.502 |  |  |  |  |  |  | 0.19 | 2.4 | 2929.9 | 395.6 | 49.2 | 4.6 | 0.5 | 5.6 | 6.2 | 125.4
Miami | Miami | 38.59214 | -94.84789 | 100 | 1 | 47 | 52 | 50 | 2018-09-26 | 14:00:00 |  |  |  | clay | 1.436 | 2.668 | 0.462 |  |  |  |  |  |  | 0.1 | 1.13 | 3950.5 | 748.7 | 134.6 | 3.1 | 0.5 | 6 | 6.4 | 240.4
Miami | Miami | 38.59214 | -94.84789 | 101 | 2 | 2 | 7 | 5 | 2018-09-26 | 14:00:00 | 5.9 | 29.7 | 64.5 | silty clay loam | 1.022 | 2.592 | 0.606 | 44.2 | 5.5 | 10 | 20.5 | 3.9 | 6.1
Miami | Miami | 38.59214 | -94.84789 | 102 | 2 | 9 | 14 | 10 | 2018-09-26 | 14:00:00 | 4.6 | 33.5 | 61.9 | silty clay loam | 1.243 | 2.620 | 0.525 | 45.1 | 5.8 | 11.7 | 23 | 3.9 | 6.3
Miami | Miami | 38.59214 | -94.84789 | 103 | 2 | 16 | 21 | 20 | 2018-09-26 | 14:00:00 | 3.3 | 42.8 | 53.8 | silty clay | 1.294 | 2.566 | 0.496 | 44.1 | 5.9 | 12.6 | 24.7 | 5.2 | 8.9
Miami | Miami | 38.59214 | -94.84789 | 104 | 2 | 47 | 52 | 50 | 2018-09-26 | 14:00:00 | 5.4 | 55.6 | 39.0 | clay | 1.340 | 2.615 | 0.488 | 48.7 | 6.8 | 17.2 | 28.6 | 6.5 | 12.9
Butler | Butler | 37.80241 | -96.88329 | 1 | 1 | 2 | 7 | 5 | 2019-06-17 | 10:00:00 |  |  |  | silty clay loam | 1.214 | 2.559 | 0.526 |  |  |  |  |  |  | 0.28 | 3.24 | 2637.7 | 356.7 | 30.1 | 5.6 | 1.5 | 5.8 | 6.4 | 276.1
Butler | Butler | 37.80241 | -96.88329 | 2 | 1 | 9 | 14 | 10 | 2019-06-17 | 10:00:00 |  |  |  | silty clay loam | 1.273 | 2.553 | 0.501 |  |  |  |  |  |  | 0.24 | 2.71 | 2601.9 | 402.3 | 35 | 5 | 0.9 | 6.2 | 6.5 | 193.7
Butler | Butler | 37.80241 | -96.88329 | 3 | 1 | 19 | 24 | 20 | 2019-06-17 | 10:00:00 |  |  |  | silty clay loam | 1.277 | 2.536 | 0.496 |  |  |  |  |  |  | 0.19 | 2.34 | 2653.8 | 496.2 | 38.7 | 4.5 | 0.7 | 5.8 | 6.3 | 158.9
Butler | Butler | 37.80241 | -96.88329 | 4 | 1 | 50 | 55 | 50 | 2019-06-17 | 10:00:00 |  |  |  | clay | 1.402 | 2.647 | 0.470 |  |  |  |  |  |  | 0.1 | 1.27 | 3142.7 | 824.2 | 72.4 | 3 | 0.4 | 5.9 | 6.4 | 233.5
Butler | Butler | 37.80241 | -96.88329 | 5 | 2 | 2 | 7 | 5 | 2019-06-17 | 10:00:00 | 13.8 | 28.1 | 58.1 | silty clay loam | 1.170 | 2.591 | 0.548 | 42.3 | 6.8 | 12.7 | 25.4 | 6.2 | 9.5
Butler | Butler | 37.80241 | -96.88329 | 6 | 2 | 8 | 13 | 10 | 2019-06-17 | 10:00:00 | 14.4 | 26.8 | 58.8 | silty clay loam | 1.224 | 2.499 | 0.510 | 39 | 6.6 | 12.3 | 23.3 | 5.8 | 8.7
Butler | Butler | 37.80241 | -96.88329 | 7 | 2 | 18 | 23 | 20 | 2019-06-17 | 10:00:00 | 11.3 | 34.7 | 54.0 | silty clay loam | 1.201 | 2.521 | 0.523 | 41 | 7.8 | 13.3 | 23.4 | 6.4 | 9.1
Butler | Butler | 37.80241 | -96.88329 | 8 | 2 | 47 | 52 | 50 | 2019-06-17 | 10:00:00 | 9.8 | 51.9 | 38.3 | clay | 1.351 | 2.665 | 0.493 | 50.1 | 14.6 | 23.1 | 29 | 13.3 | 16.7
Viola | Sumner | 37.45974 | -97.6245 | 9 | 1 | 2 | 7 | 5 | 2019-06-17 | 13:00:00 |  |  |  | silt loam | 1.267 | 2.627 | 0.518 |  |  |  |  |  |  | 0.13 | 1.51 | 1459.7 | 208.1 | 31.3 | 2.7 | 54.9 | 5.6 | 6.3 | 152.1
Viola | Sumner | 37.45974 | -97.6245 | 10 | 1 | 8 | 13 | 10 | 2019-06-17 | 13:00:00 |  |  |  | silt loam | 1.337 | 2.639 | 0.493 |  |  |  |  |  |  | 0.07 | 1.1 | 1039.2 | 218.6 | 23.3 | 2.1 | 60.1 | 4.6 | 6 | 121.8
Viola | Sumner | 37.45974 | -97.6245 | 11 | 1 | 17 | 22 | 20 | 2019-06-17 | 13:00:00 |  |  |  | silt loam | 1.401 | 2.653 | 0.472 |  |  |  |  |  |  | 0.08 | 1.08 | 1679.1 | 452.8 | 24.4 | 2.1 | 14.8 | 5 | 6.2 | 146.3
Viola | Sumner | 37.45974 | -97.6245 | 12 | 1 | 47 | 52 | 50 | 2019-06-17 | 13:00:00 |  |  |  | silty clay | 1.468 | 2.683 | 0.453 |  |  |  |  |  |  | 0.06 | 0.6 | 3302.8 | 1397.8 | 162.5 | 1.8 | 0.7 | 6.9 | 7 | 279
Viola | Sumner | 37.45974 | -97.6245 | 13 | 2 | 2 | 7 | 5 | 2019-06-17 | 13:00:00 | 17.6 | 19.0 | 63.4 | silt loam | 1.360 | 2.617 | 0.480 | 45.6 | 8.5 | 15 | 26.1 | 6.6 | 9.5
Viola | Sumner | 37.45974 | -97.6245 | 14 | 2 | 8 | 13 | 10 | 2019-06-17 | 13:00:00 | 16.3 | 19.0 | 64.6 | silt loam | 1.437 | 2.624 | 0.452 | 47.9 | 8.2 | 14.5 | 26.4 | 6.2 | 8.9
Viola | Sumner | 37.45974 | -97.6245 | 15 | 2 | 18 | 23 | 20 | 2019-06-17 | 13:00:00 | 17.2 | 24.2 | 58.6 | silt loam | 1.472 | 2.653 | 0.445 | 44.5 | 7.1 | 12.8 | 29.6 | 5.2 | 7.4
Viola | Sumner | 37.45974 | -97.6245 | 16 | 2 | 47 | 52 | 50 | 2019-06-17 | 13:00:00 | 9.7 | 46.8 | 43.5 | silty clay | 1.464 | 2.720 | 0.462 | 54.8 | 7 | 14.3 | 25.8 | 5.6 | 9.2
Harper | Harper | 37.06477 | -98.08467 | 17 | 1 | 3 | 8 | 5 | 2019-06-17 | 15:00:00 |  |  |  | silt loam | 1.396 | 2.688 | 0.480 |  |  |  |  |  |  | 0.16 | 2.07 | 1585.9 | 312.3 | 13 | 3.1 | 3.2 | 6.9 | 7.1 | 340.2
Harper | Harper | 37.06477 | -98.08467 | 18 | 1 | 8 | 13 | 10 | 2019-06-17 | 15:00:00 |  |  |  | silt loam | 1.297 | 2.686 | 0.517 |  |  |  |  |  |  | 0.13 | 1.7 | 1619.9 | 323.6 | 13 | 2.6 | 1.8 | 6.8 | 7.1 | 286.8
Harper | Harper | 37.06477 | -98.08467 | 19 | 1 | 18 | 23 | 20 | 2019-06-17 | 15:00:00 |  |  |  | silt loam | 1.232 | 2.630 | 0.532 |  |  |  |  |  |  | 0.11 | 1.48 | 1675.4 | 328.8 | 13.8 | 2.6 | 1.4 | 6.9 | 7.2 | 216.8
Harper | Harper | 37.06477 | -98.08467 | 20 | 1 | 48 | 53 | 50 | 2019-06-17 | 15:00:00 |  |  |  | silt loam | 1.316 | 2.680 | 0.509 |  |  |  |  |  |  | 0.06 | 0.66 | 1622.4 | 350.6 | 17.1 | 1.5 | 1.1 | 6.8 | 7.2 | 122.2
Harper | Harper | 37.06477 | -98.08467 | 21 | 2 | 2 | 7 | 5 | 2019-06-17 | 15:00:00 | 16.5 | 11.4 | 72.1 | silt loam | 1.373 | 2.622 | 0.476 | 51.3 | 13.6 | 19.3 | 27.6 | 9.9 | 12.8
Harper | Harper | 37.06477 | -98.08467 | 22 | 2 | 9 | 14 | 10 | 2019-06-17 | 15:00:00 | 20.8 | 16.5 | 62.8 | silt loam | 1.256 | 2.763 | 0.545 | 41.7 | 13.3 | 19.1 | 25.3 | 9.6 | 11
Harper | Harper | 37.06477 | -98.08467 | 23 | 2 | 18 | 23 | 20 | 2019-06-17 | 15:00:00 | 15.7 | 19.0 | 65.3 | silt loam | 1.288 | 2.670 | 0.517 | 44.4 | 15.8 | 21.7 | 28.7 | 11.3 | 13.2
Harper | Harper | 37.06477 | -98.08467 | 24 | 2 | 48 | 53 | 50 | 2019-06-17 | 15:00:00 | 17.4 | 22.9 | 59.8 | silt loam | 1.603 | 2.676 | 0.401 | 47.1 | 19.8 | 25.9 | 29.3 | 14.8 | 15.8
Lake City | Barber | 37.30903 | -98.79332 | 25 | 1 | 2 | 7 | 5 | 2019-06-17 | 17:00:00 |  |  |  | sandy loam | 1.626 | 2.639 | 0.384 |  |  |  |  |  |  | 0.08 | 0.82 | 1118.8 | 146.1 | 14.4 | 1.8 | 5.2 | 7.1 | 7.2 | 210.9
Lake City | Barber | 37.30903 | -98.79332 | 26 | 1 | 8 | 13 | 10 | 2019-06-17 | 17:00:00 |  |  |  | sandy loam | 1.594 | 2.716 | 0.413 |  |  |  |  |  |  | 0.05 | 0.73 | 1105.6 | 145.7 | 12.3 | 1.5 | 2.4 | 7 | 7.2 | 196.5
Lake City | Barber | 37.30903 | -98.79332 | 27 | 1 | 18 | 23 | 20 | 2019-06-17 | 17:00:00 |  |  |  | sandy loam | 1.566 | 2.637 | 0.406 |  |  |  |  |  |  | 0.05 | 0.61 | 1274.5 | 153.7 | 20.7 | 1.4 | 1.8 | 7.1 | 7.3 | 186.3
Lake City | Barber | 37.30903 | -98.79332 | 28 | 1 | 48 | 53 | 50 | 2019-06-17 | 17:00:00 |  |  |  | sandy loam | 1.819 | 2.679 | 0.321 |  |  |  |  |  |  | 0.01 | 0.32 | 977.7 | 150.2 | 22.4 | 0.9 | 3.4 | 7.6 | 7.4 | 156.5
Lake City | Barber | 37.30903 | -98.79332 | 29 | 2 | 3 | 8 | 5 | 2019-06-17 | 17:00:00 | 61.5 | 12.6 | 25.9 | sandy loam | 1.619 | 2.705 | 0.401 | 47.7 | 12.1 | 17.4 | 28.7 | 9.4 | 11.8
Lake City | Barber | 37.30903 | -98.79332 | 30 | 2 | 8 | 13 | 10 | 2019-06-17 | 17:00:00 | 65.3 | 11.3 | 23.3 | sandy loam | 1.748 | 2.621 | 0.333 | 43.2 | 11.9 | 17.2 | 28.4 | 8.6 | 10.7
Lake City | Barber | 37.30903 | -98.79332 | 31 | 2 | 18 | 23 | 20 | 2019-06-17 | 17:00:00 | 66.6 | 12.6 | 20.8 | sandy loam | 1.793 | 2.691 | 0.334 | 41 | 12.1 | 16.9 | 30.2 | 8.9 | 10.7
Lake City | Barber | 37.30903 | -98.79332 | 32 | 2 | 48 | 53 | 50 | 2019-06-17 | 17:00:00 | 72.3 | 12.6 | 15.1 | sandy loam | 1.859 | 2.738 | 0.321 | 47.2 | 16.3 | 21.1 | 34.5 | 11.8 | 14.2
Ashland 8S | Clark | 37.06488 | -99.75115 | 33 | 1 | 2 | 7 | 5 | 2019-06-18 | 9:00:00 |  |  |  | clay loam | 1.480 | 2.630 | 0.437 |  |  |  |  |  |  | 0.17 | 2.68 | 4635.7 | 514.7 | 89.3 | 3.3 | 150.8 | 7.8 | 7.4 | 644.3
Ashland 8S | Clark | 37.06488 | -99.75115 | 34 | 1 | 7 | 12 | 10 | 2019-06-18 | 9:00:00 |  |  |  | clay loam | 1.469 | 2.657 | 0.447 |  |  |  |  |  |  | 0.14 | 2.42 | 4539.6 | 494.9 | 58.4 | 2.8 | 119.8 | 8 | 7.5 | 645.7
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

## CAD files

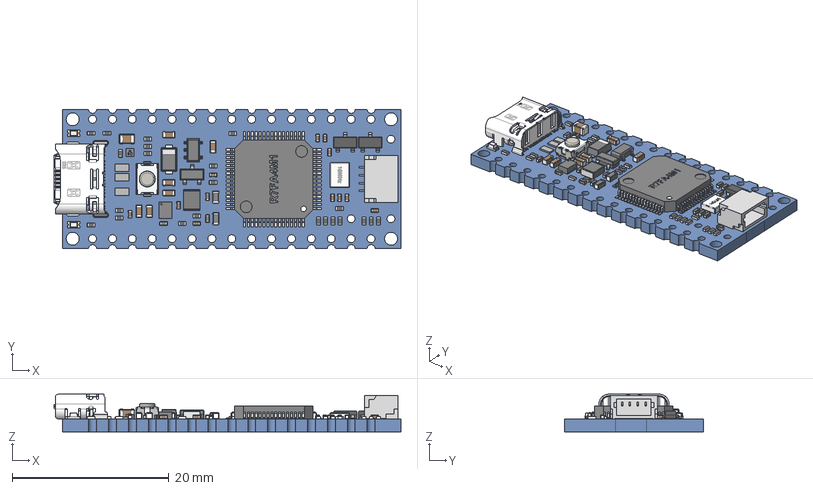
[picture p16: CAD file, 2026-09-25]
hat/mechanical/sources/ABX00142.step
44.3 x 17.8 x 4.81 mm
CAP-0402 x 14
FER-0603 x 2
CAP-0603 x 6
Extruded x 9
SOT-23 x 2
lead x 2
RES-0402 x 22
Leader x 67
sot25
SM04B-SRSS-TB_RGB12040119
quartz_3_2__2_5_16MHz v2
HSMx-190 x 2
PTS820J20KSMTRLFS
CX90B-16P_3D
CAP-0805

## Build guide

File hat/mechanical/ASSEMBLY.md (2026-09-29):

# Compact Nano R4 assembly

Use a headerless **Arduino Nano R4 ABX00142** with its populated face toward the HAT's top face. The HAT is exactly the Nano's outline (43.18 × 17.78 mm) with the Nano's pin positions, and carries parts on both faces: low parts on the top face inside the gap, and the power stage, INA226 and thermistor dividers on its outer (bottom) face, which the potting covers. Join the boards permanently with **two Samtec HTSW-115-07-T-S male headers**, soldered into both boards, while a fixture holds the facing PCB surfaces **4.00 mm apart**. Both outside PCB surfaces remain accessible for soldering. This arrangement avoids tall sockets and keeps the electronics compact for potting.

These are soldered electrical joints. Sliding ordinary pins into bare plated holes and relying on epoxy does not provide a reliable electrical connection.

[Open the side-view assembly drawing](nano-hat-stack.svg) for the face-inward orientation, header direction, solder locations and thickness budget.

## Parts and dimensions

| Item | Selected specification |
|---|---|
| Controller | Arduino Nano R4 ABX00142, without factory headers |
| Interconnects | 2 × Samtec HTSW-115-07-T-S; 15 pins per strip, 2.54 mm pitch |
| Header pins | 0.635 mm square, 5.84 mm long post, 2.54 mm solder tail |
| Header insulator height | 2.54 mm, inside the board gap |
| Facing board spacing | 4.00 mm, controlled by the assembly fixture |
| HAT finished holes / pads | 1.10 mm / 1.80 mm; hole diameter is the HAT designer's solder allowance |
| Exterior solid pin ends | Trim to no more than 0.50 mm beyond either outside PCB surface |

The [Samtec TSW/HTSW catalog](https://suddendocs.samtec.com/catalog_english/tsw_th.pdf) supplies the pin dimensions and identifies the HTSW LCP housing as suitable for lead-free soldering. The standard TSW PBT version is not the selected substitute. The [authorized Farnell listing](https://uk.farnell.com/samtec/htsw-115-07-t-s/pin-header-15pos-1row-2-54mm-tht/dp/3752524) showed a one-piece minimum, £0.861 unit price and a three-week stated lead time when checked on 2026-09-23. Prices and delivery are purchasing snapshots, not guarantees; no parts have been ordered.

## Thickness budget

The [official Arduino STEP model](https://docs.arduino.cc/resources/models/ABX00142-step.zip) has a 1.6368 mm board. The USB shell reaches 3.17 mm above its populated face, the Qwiic connector 2.975 mm, the reset switch 2.005 mm and the microcontroller 1.67 mm. These parts sit inside the 4.00 mm gap; the HAT layout reserves clearance opposite the tall connectors.

| Contribution | Thickness |
|---|---:|
| HAT PCB | 0.800 mm |
| Facing gap | 4.000 mm |
| Nano PCB from nominal CAD | 1.637 mm |
| Nano outer face: pin/solder allowance | 0.500 mm |
| HAT outer face: tallest part envelope (10 µF 0805 C17, 1.45 mm maximum + 0.10 mm solder; the check budgets every other outer-face part at 1.50 mm) | 1.550 mm |
| Epoxy cover target, 1 mm on each face | 2.000 mm |
| **Nominal potted stack** | **10.487 mm** |

The HAT's outer-face parts, not its 0.50 mm pin tails or the field wires, set that face's exterior allowance. **The 10.5 mm potting mold target is therefore met only nominally with a full 1 mm cover on both faces.** Tolerance has to come out of the cover (0.75 mm over the tallest HAT outer-face part gives 10.24 mm), or the mold must be made thicker; decide this from the first assembled unit. A guaranteed 10.0 mm maximum is not possible with parts on both HAT faces. The field wires lie on the HAT's outer face between the cable end and the cable holes, where there are no parts: three separate bare 22-AWG conductors (about 0.64 mm diameter) bent flat, with **no more than 0.80 mm total wire/insulation/solder projection**, stay below the 1.55 mm part allowance. Route them in separate parallel lanes toward the USB end, maintaining their separation from the 4 mm terminal pitch; do not cross or stack them. A thin insulating strip underneath the bare conductors prevents contact with exposed copper or damaged solder mask. Include that strip in the 0.80 mm limit.

Start the full wire insulation beyond the PCB edge and bring the three insulated leads out side-by-side. A bundle of insulated wires underneath the board does **not** fit this thickness budget. The cable transition and strain relief may need a local relief in the mold; size it from the actual cable. The 10.5 mm target applies to the main head body, not a verified cable gland envelope. Clean, inspect and test the terminations before potting; encapsulate the separated conductors completely. Solder mask is not a waterproof seal.

The body PCB remains 43.18 × 17.78 mm. The finished epoxy head is longer and wider: the reference design includes 8 mm of needle root embedment beyond the body, and the Nano USB shell overhangs the opposite edge by 1.112 mm. Allowing about 1 mm side coverage gives a preliminary mold envelope of **54 × 21 × 10.5 mm**. Its width includes the two outer needle tubes, 2.77 mm outside diameter at ±8 mm centers. The exposed needles extend beyond that head.

## Assembly sequence

1. Inspect and program the Nano through its USB-C connector before final assembly. Use the headerless ABX00142; the factory-header version is not the intended stack.
2. Put the two header strips on the HAT's top face (the face toward the Nano), with short tails through the HAT and long posts toward the Nano. Insert the Nano populated face downward, USB at the cable end. On the HAT's outer face the nearest parts (the divider capacitors) sit about 0.9 mm from the header pads; use a fine soldering tip there.
3. Hold a measured 4.00 mm gap with a removable fixture that does not press on components. Align both board outlines and tack opposing corner pins. Check the gap and squareness before completing all 60 header solder joints.
4. Trim the solid exterior pin ends to the stated limit without stressing solder joints. Inspect the joints and confirm no pin bridges or protrusions exceed the envelope.
5. Solder and strain-relieve the field wires using the separate flat-conductor routing above. Measure the exterior projection and check the actual insulated cable exit against the mold. Program and run the complete sensor, including a heater pulse, before encapsulation.
6. Mask connector cavities against resin entry and pot the tested assembly. This sealed version assumes USB programming is completed before potting; it does not provide a permanently exposed waterproof USB port.

## Mechanical evidence and limitations

`nano-r4-envelope.json` contains nominal envelopes for the board and 63 components extracted from the official STEP assembly, with source hash. The coordinate mapping to KiCad's screen-down Y convention is **HAT X = Nano X, HAT Y = Nano Y − 8.89** for this face-down installation. Digital row J3 is at +7.62 mm and analog/power row J4 at −7.62 mm; the [official pinout](https://docs.arduino.cc/resources/pinouts/ABX00142-full-pinout.pdf) and power/built-in LED positions were checked independently.

The extraction uses transformed solid vertices, not a full tolerance or resin-flow simulation. The automated assembly check adds package and placement allowances; physical first-assembly verification is still required before committing a mold. Field wires and cable strain relief are not modeled. Connector soldering, board bow and potting cure stress are not established by a CAD pass.

The investigated Mill-Max socket pair could provide a 3.94 mm gap, but was rejected as the default because the exact short socket was not stocked in small quantities at the checked distributor. Its hollow socket tails also cannot be treated like ordinary solid pins for trimming. Direct soldered headers retain the compact geometry with lower cost and no separable contact inside the permanently potted sensor.

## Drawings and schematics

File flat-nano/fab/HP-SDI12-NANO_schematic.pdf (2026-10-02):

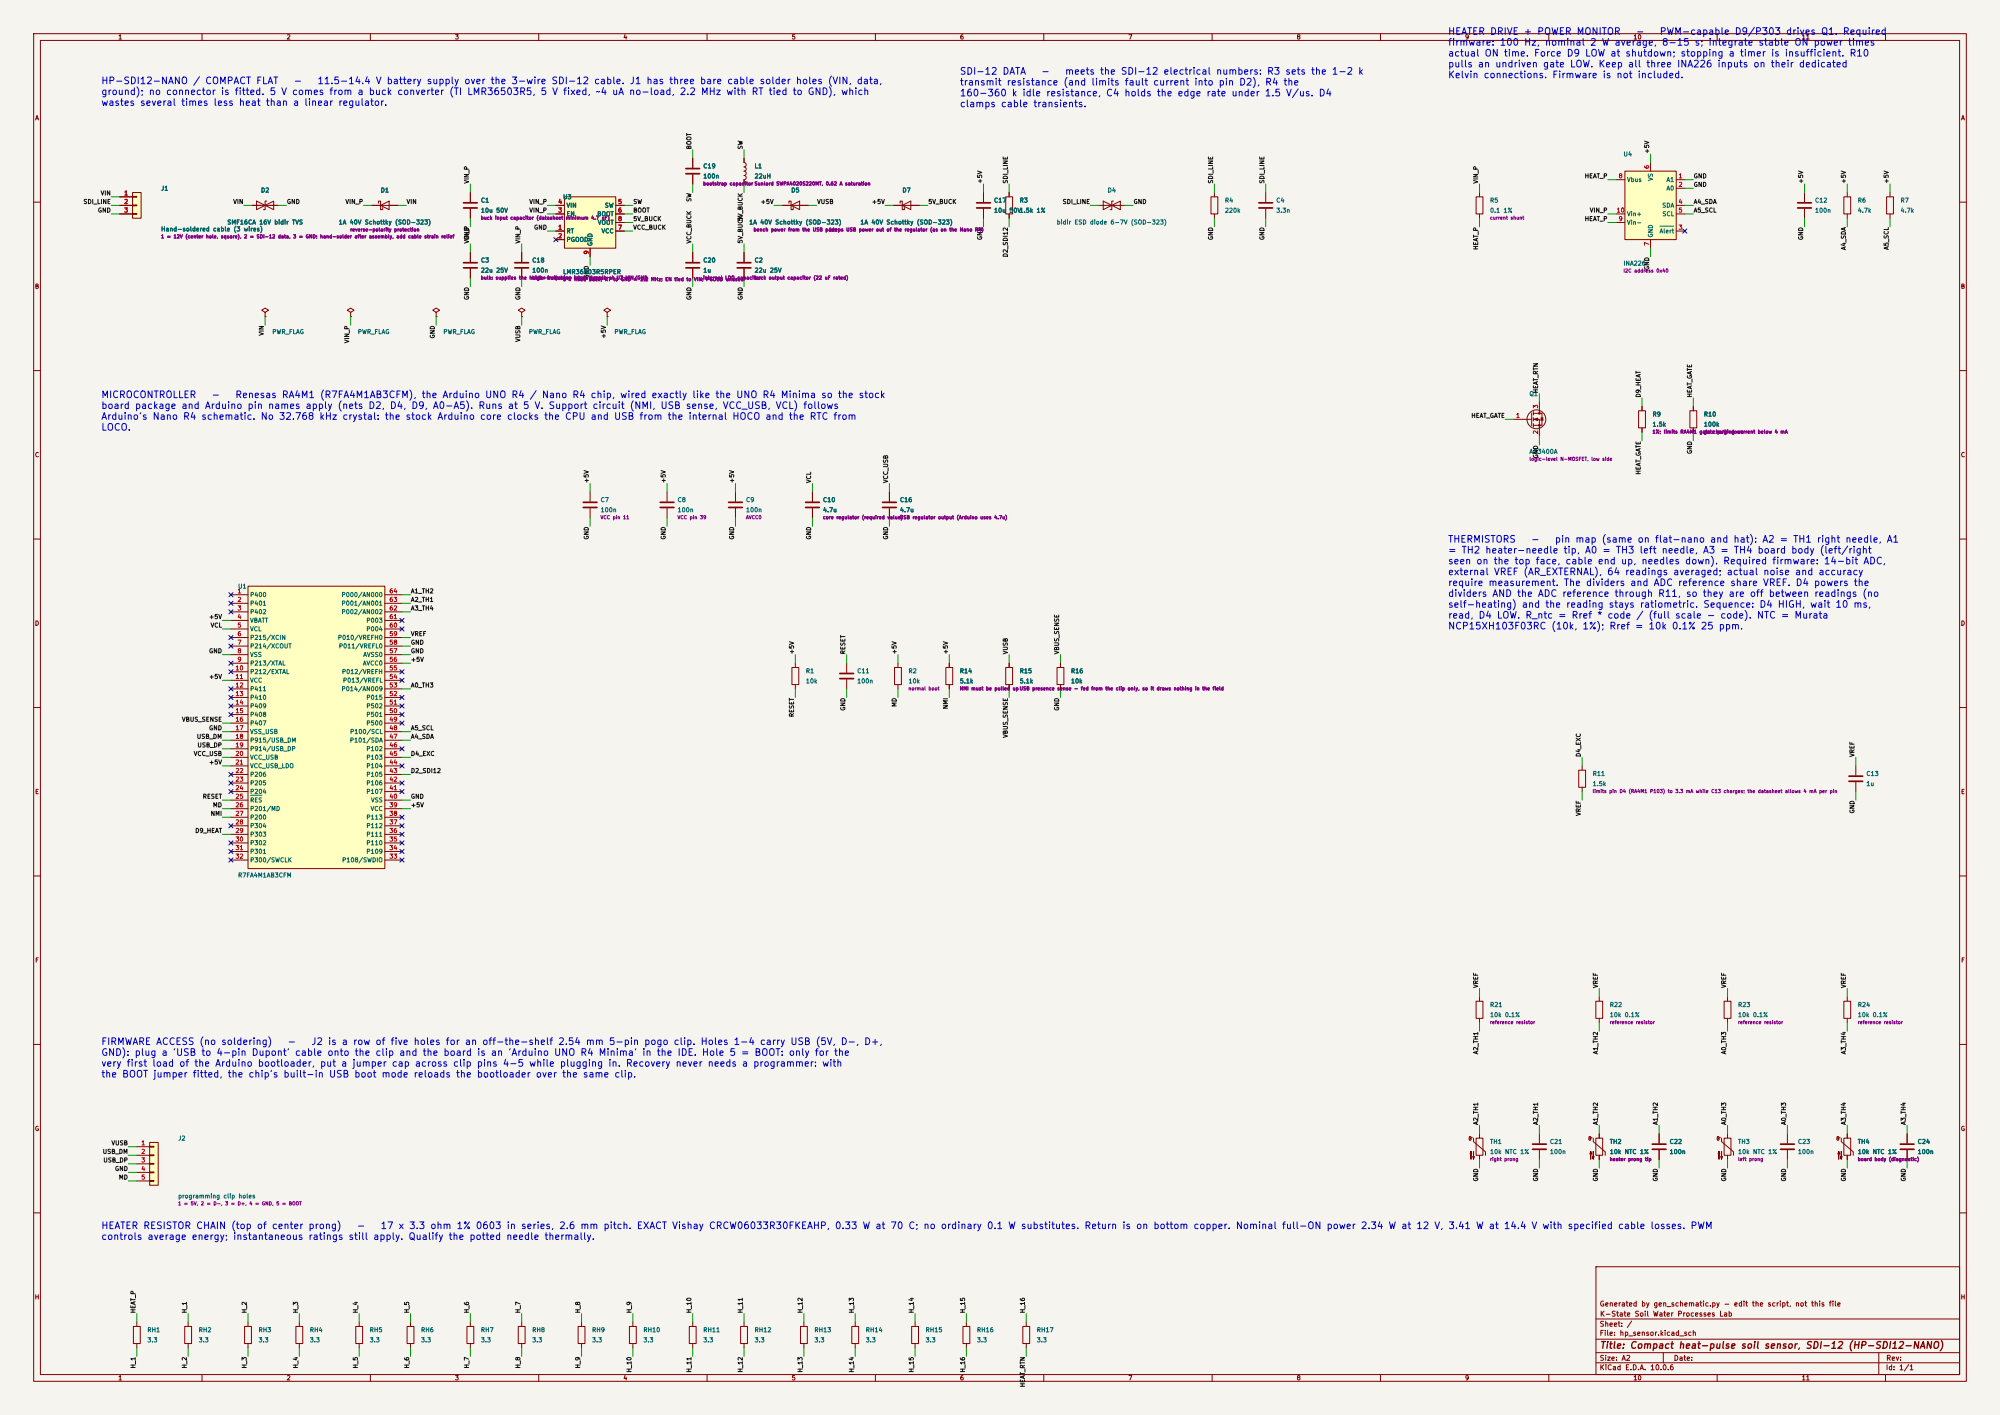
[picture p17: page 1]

firmware: 100 Hz, nominal 2 W average, 8-15 s; integrate stable ON power times
actual ON time. Force D9 LOW at shutdown; stopping a timer is insufficient. R10
pulls an undriven gate LOW. Keep all three INA226 inputs on their dedicated
Kelvin connections. Firmware is not included.

transmit resistance (and limits fault current into pin D2), R4 the
160-360 k idle resistance, C4 holds the edge rate under 1.5 V/us. D4
clamps cable transients.
Sunlord SWPA4020S220MT, 0.62 A saturation C10

ground); no connector is fitted. 5 V comes from a buck converter (TI LMR36503R5, 5 V fixed, ~4 uA no-load, 2.2 MHz with RT tied to GND), which
wastes several times less heat than a linear regulator.

keeps USB power out of the regulator (as on the Nano R4) L1

J1Hand-soldered cable (3 wires) 1 = 12V (center hole, square), 2 = SDI-12 data, 3 = GND; hand-solder after assembly, add cable strain relief 1

J1Hand-soldered cable (3 wires) 1 = 12V (center hole, square), 2 = SDI-12 data, 3 = GND; hand-solder after assembly, add cable strain relief D1
GNDH_3 H_3

buck output capacitor (22 uF rated) D2

high-frequency input bypass at U3 VIN/GND U3

1A 40V Schottky (SOD-323) bench power from the USB pads C10

1A 40V Schottky (SOD-323) bench power from the USB pads C18

bulk: supplies the heater switching edges locally C18

bulk: supplies the heater switching edges locally PWR_FLAG

high-frequency input bypass at U3 VIN/GND PWR_FLAG

board package and Arduino pin names apply (nets D2, D4, D9, A0-A5). Runs at 5 V. Support circuit (NMI, USB sense, VCC_USB, VCL) follows
Arduino's Nano R4 schematic. No 32.768 kHz crystal: the stock Arduino core clocks the CPU and USB from the internal HOCO and the RTC from
LOCO.

1%; limits RA4M1 gate charging current below 4 mA 1

1%; limits RA4M1 gate charging current below 4 mA R10

core regulator (required value)C16
core regulator (required value)

USB regulator output (Arduino uses 4.7u)

USB regulator output (Arduino uses 4.7u) C11

external VREF (AR_EXTERNAL), 64 readings averaged; actual noise and accuracy
require measurement. The dividers and ADC reference share VREF. D4 powers the
dividers AND the ADC reference through R11, so they are off between readings (no
self-heating) and the reading stays ratiometric. Sequence: D4 HIGH, wait 10 ms,
read, D4 LOW. R_ntc = Rref * code / (full scale - code). NTC = Murata
NCP15XH103F03RC (10k, 1%); Rref = 10k 0.1% 25 ppm.

5.1k USB presence sense - fed from the clip only, so it draws nothing in the field R16

GND): plug a 'USB to 4-pin Dupont' cable onto the clip and the board is an 'Arduino UNO R4 Minima' in the IDE. Hole 5 = BOOT: only for the
very first load of the Arduino bootloader, put a jumper cap across clip pins 4-5 while plugging in. Recovery never needs a programmer: with
the BOOT jumper fitted, the chip's built-in USB boot mode reloads the bootloader over the same clip.

controls average energy; instantaneous ratings still apply. Qualify the potted needle thermally.

Generated by gen_schematic.py - edit the script, not this file
K-State Soil Water Processes Lab
Sheet: /
File: hp_sensor.kicad_sch
Title: Compact heat-pulse soil sensor, SDI-12 (HP-SDI12-NANO)

Size: A2 | Rev:
KiCad E.D.A. 10.0.6 | Id: 1/1

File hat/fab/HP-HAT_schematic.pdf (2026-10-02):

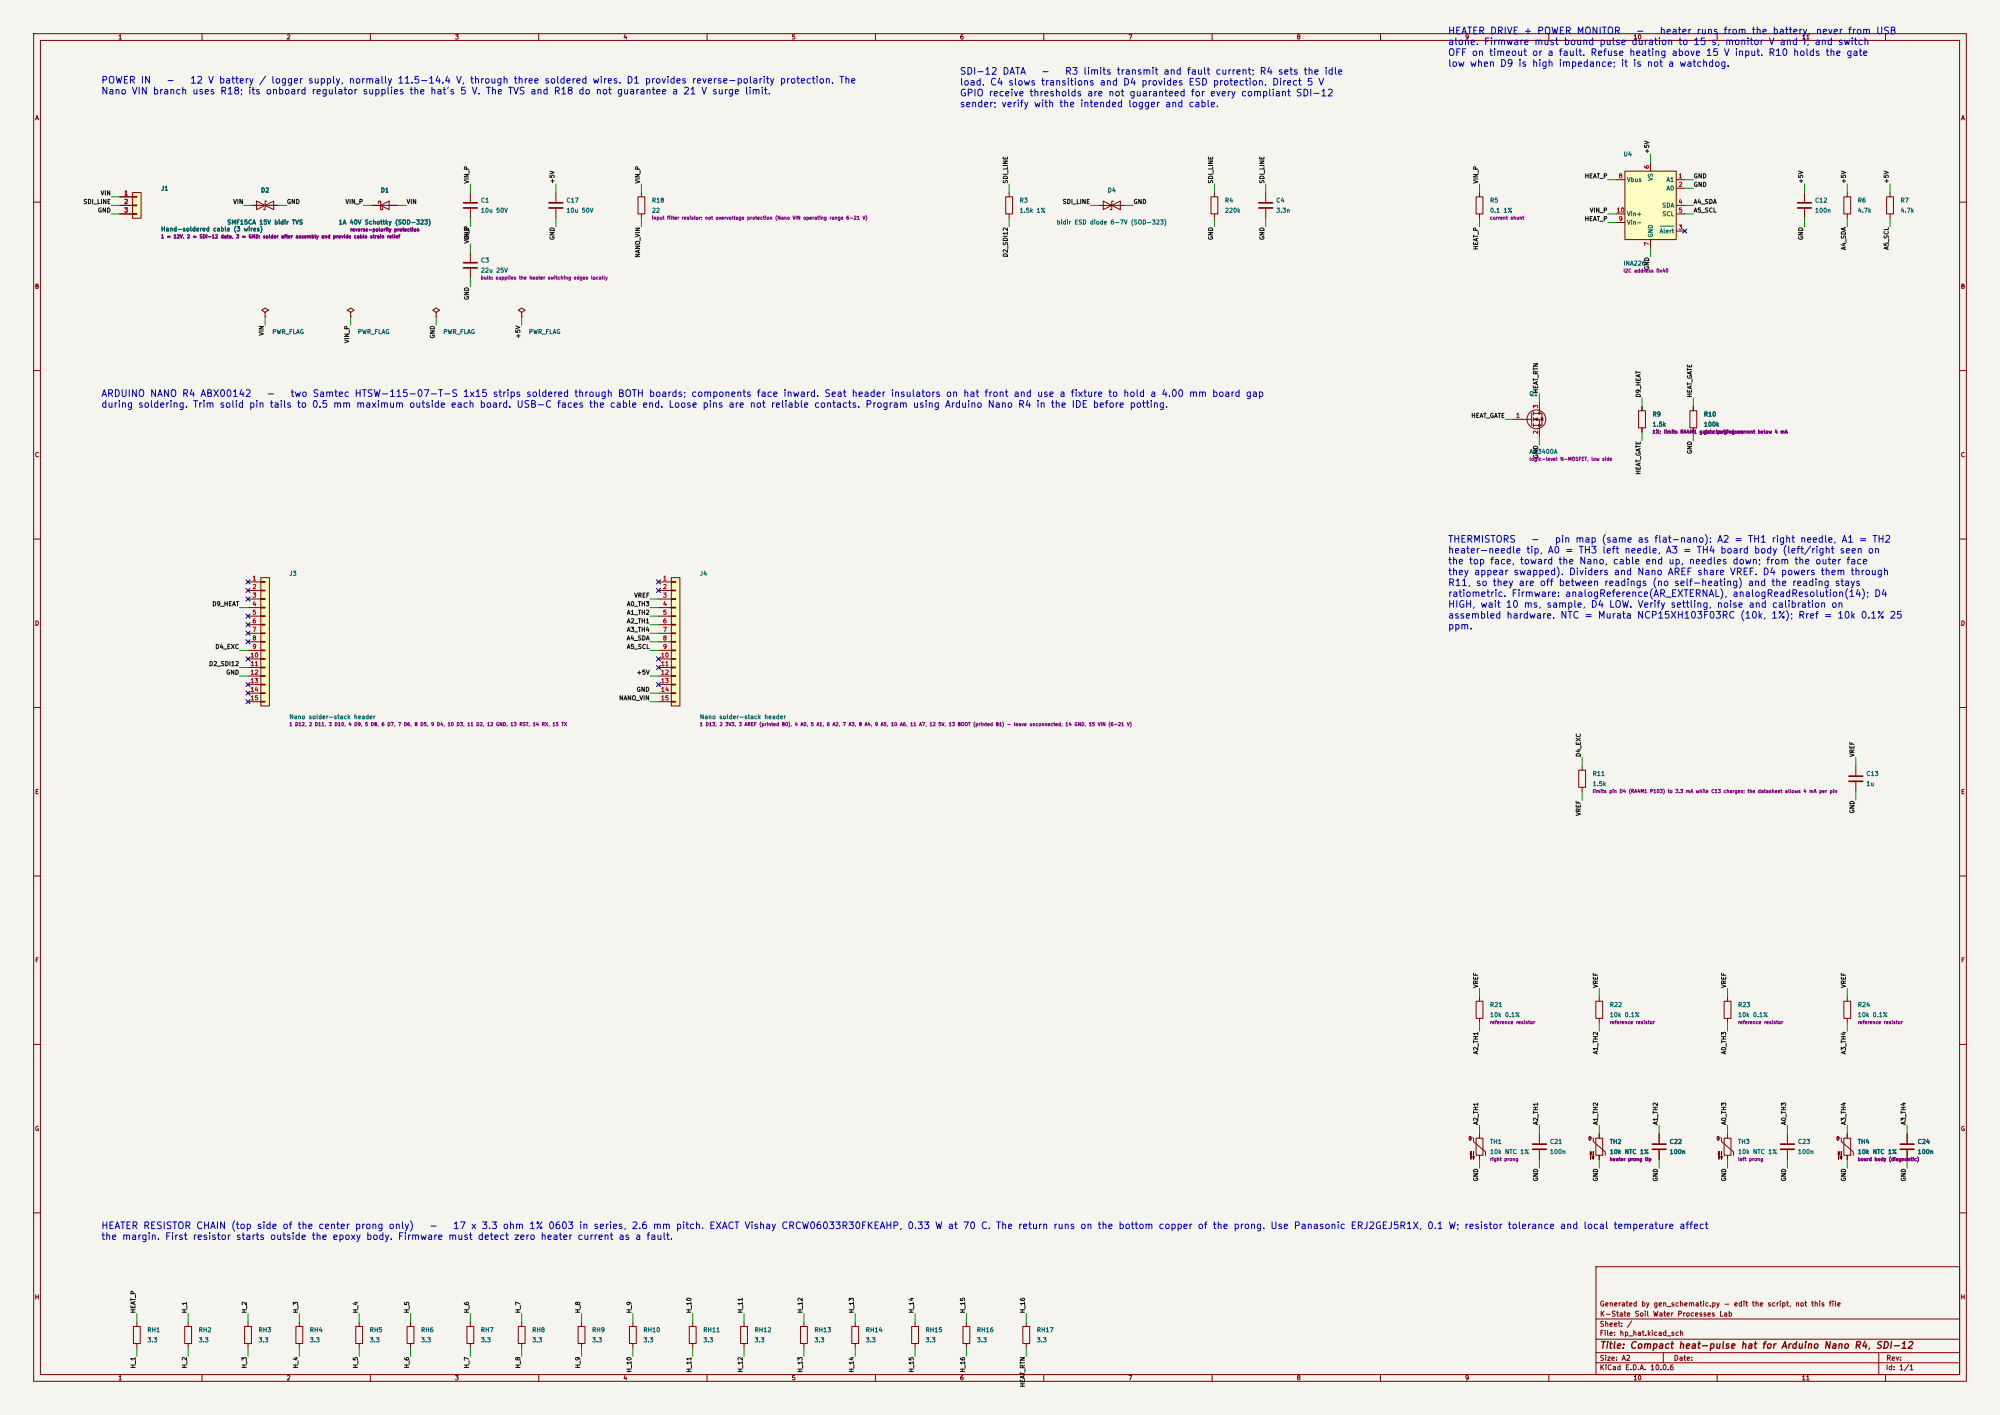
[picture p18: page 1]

alone. Firmware must bound pulse duration to 15 s, monitor V and I, and switch
OFF on timeout or a fault. Refuse heating above 15 V input. R10 holds the gate
low when D9 is high impedance; it is not a watchdog.

load. C4 slows transitions and D4 provides ESD protection. Direct 5 V
GPIO receive thresholds are not guaranteed for every compliant SDI-12
sender; verify with the intended logger and cable.

Nano VIN branch uses R18; its onboard regulator supplies the hat's 5 V. The TVS and R18 do not guarantee a 21 V surge limit.

J1Hand-soldered cable (3 wires) 1 = 12V, 2 = SDI-12 data, 3 = GND; solder after assembly and provide cable strain relief 1
bidir ESD diode 6-7V (SOD-323) 1

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

bulk: supplies the heater switching edges locally

during soldering. Trim solid pin tails to 0.5 mm maximum outside each board. USB-C faces the cable end. Loose pins are not reliable contacts. Program using Arduino Nano R4 in the IDE before potting.

1%; limits RA4M1 gate charging current below 4 mA

1%; limits RA4M1 gate charging current below 4 mA R10

logic-level N-MOSFET, low side

heater-needle tip, A0 = TH3 left needle, A3 = TH4 board body (left/right seen on
the top face, toward the Nano, cable end up, needles down; from the outer face
they appear swapped). Dividers and Nano AREF share VREF. D4 powers them through
R11, so they are off between readings (no self-heating) and the reading stays
ratiometric. Firmware: analogReference(AR_EXTERNAL), analogReadResolution(14); D4
HIGH, wait 10 ms, sample, D4 LOW. Verify settling, noise and calibration on
assembled hardware. NTC = Murata NCP15XH103F03RC (10k, 1%); Rref = 10k 0.1% 25
ppm.

J3Nano solder-stack header 1 D12, 2 D11, 3 D10, 4 D9, 5 D8, 6 D7, 7 D6, 8 D5, 9 D4, 10 D3, 11 D2, 12 GND, 13 RST, 14 RX, 15 TX

J4Nano solder-stack header 1 D13, 2 3V3, 3 AREF (printed B0), 4 A0, 5 A1, 6 A2, 7 A3, 8 A4, 9 A5, 10 A6, 11 A7, 12 5V, 13 BOOT (printed B1) - leave unconnected, 14 GND, 15 VIN (6-21 V)

the margin. First resistor starts outside the epoxy body. Firmware must detect zero heater current as a fault.

Generated by gen_schematic.py - edit the script, not this file
K-State Soil Water Processes Lab
Sheet: /
File: hp_hat.kicad_sch
Title: Compact heat-pulse hat for Arduino Nano R4, SDI-12

Size: A2 | Rev:
KiCad E.D.A. 10.0.6 | Id: 1/1

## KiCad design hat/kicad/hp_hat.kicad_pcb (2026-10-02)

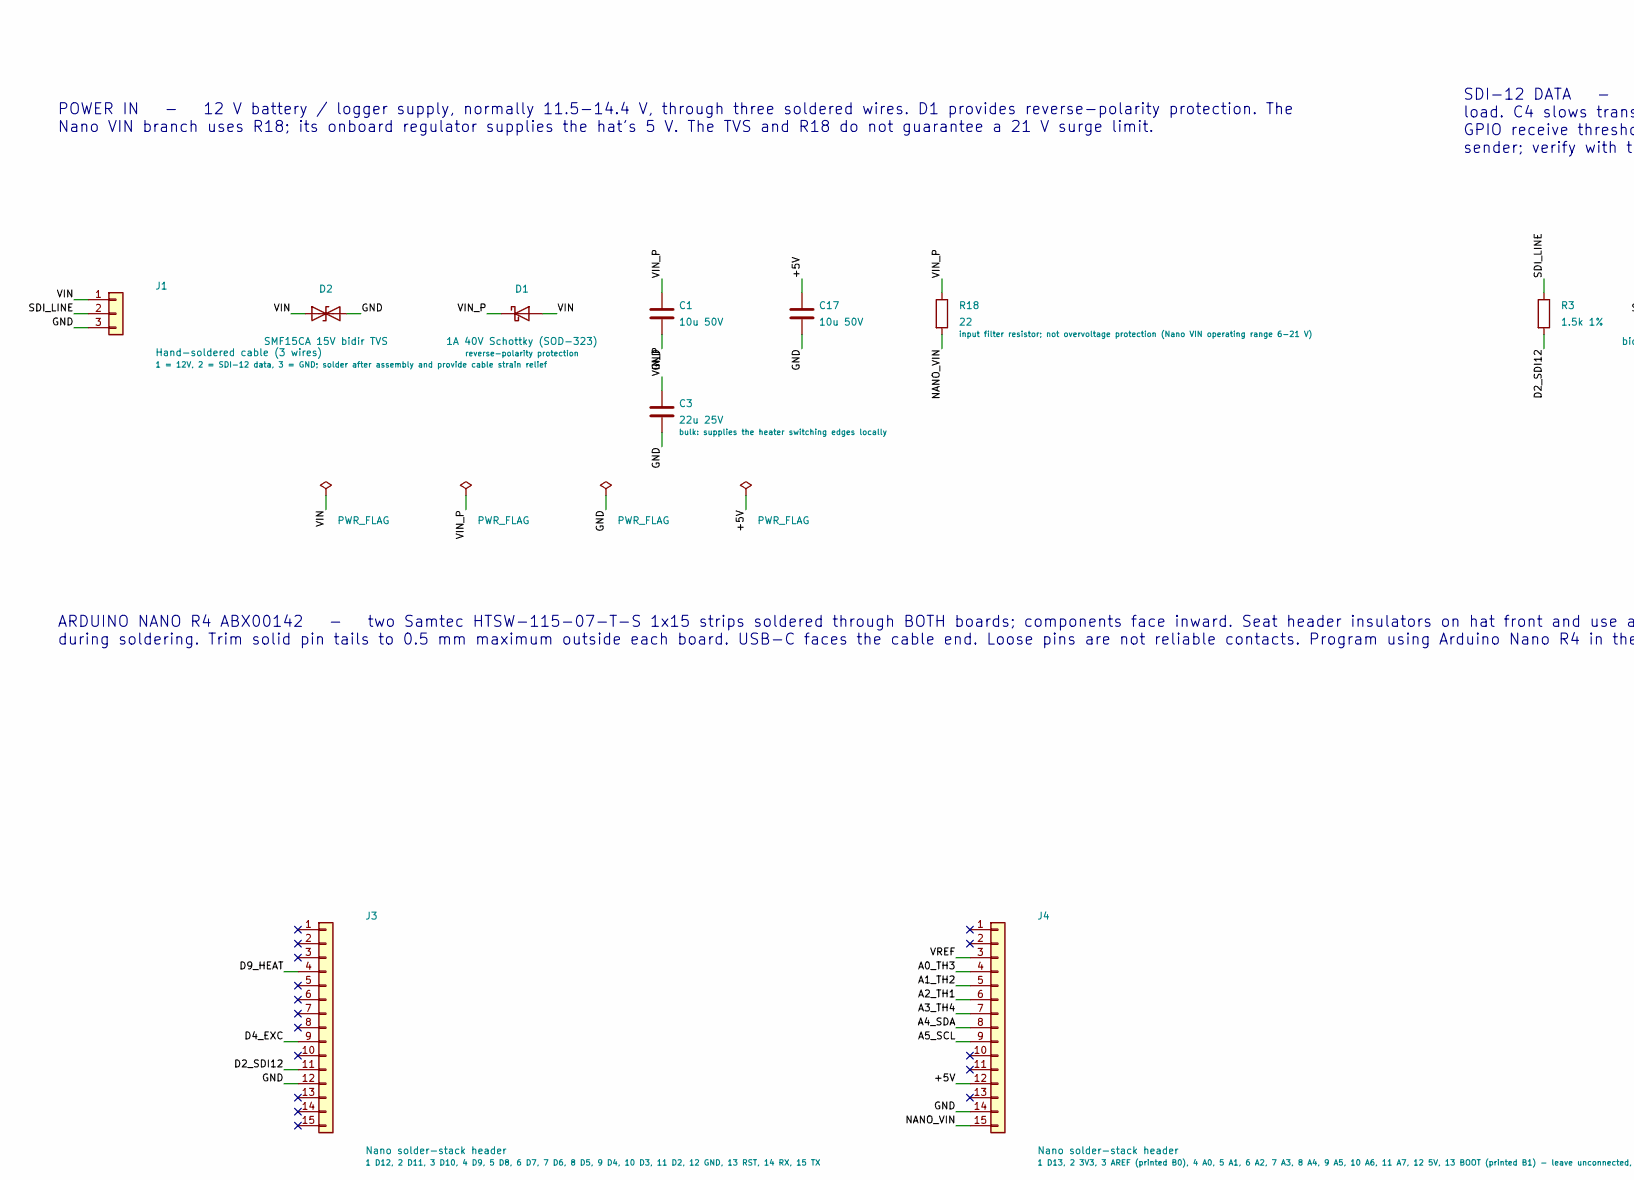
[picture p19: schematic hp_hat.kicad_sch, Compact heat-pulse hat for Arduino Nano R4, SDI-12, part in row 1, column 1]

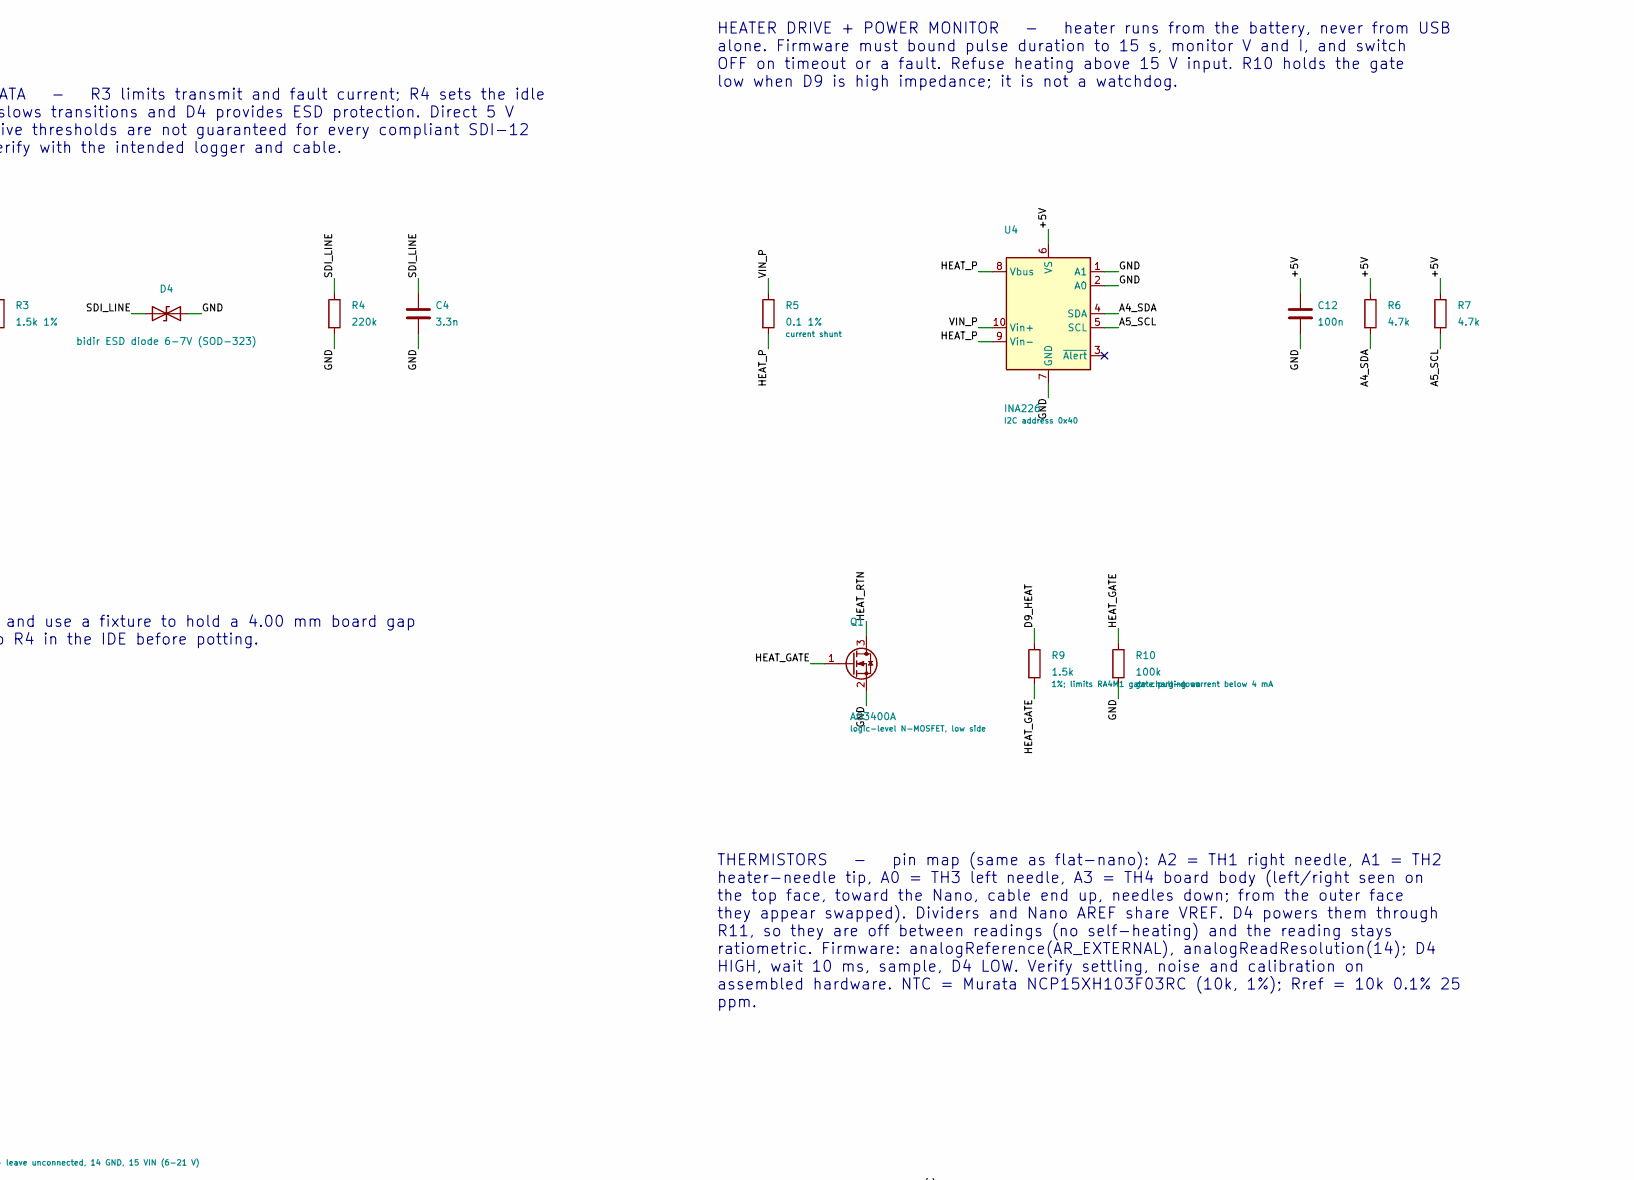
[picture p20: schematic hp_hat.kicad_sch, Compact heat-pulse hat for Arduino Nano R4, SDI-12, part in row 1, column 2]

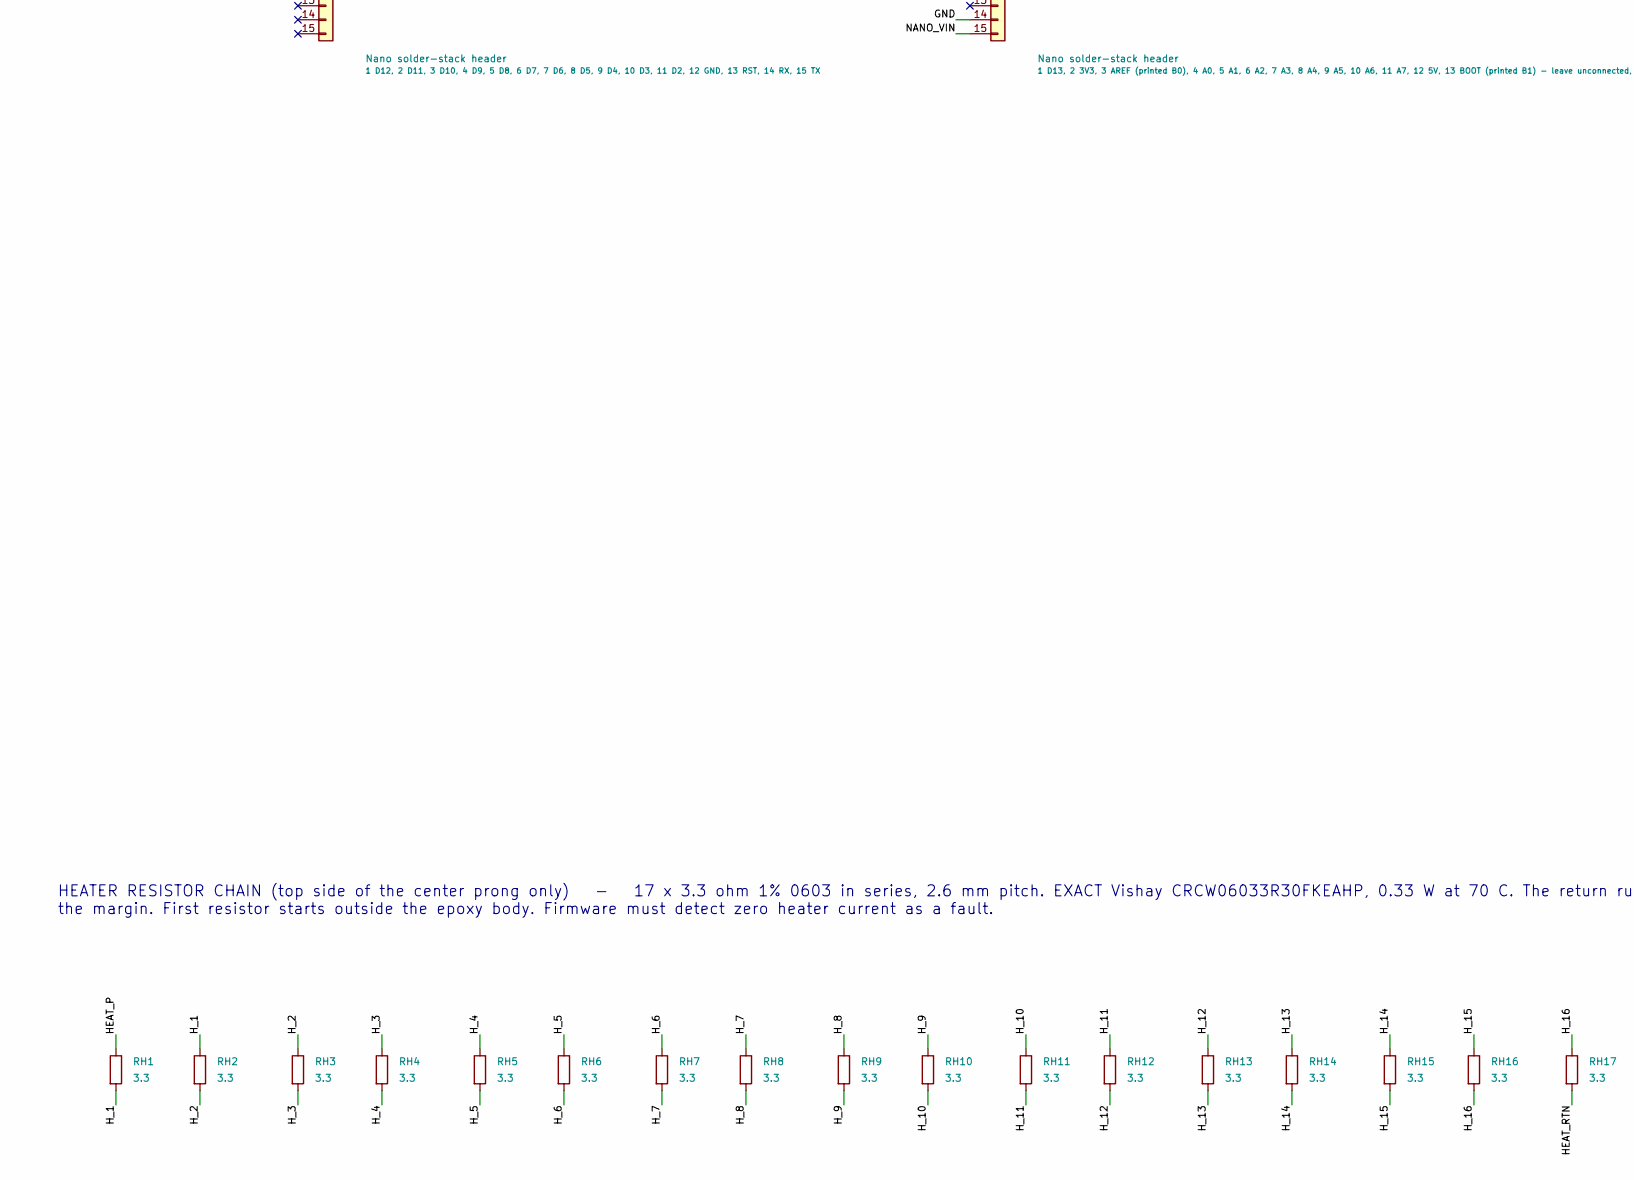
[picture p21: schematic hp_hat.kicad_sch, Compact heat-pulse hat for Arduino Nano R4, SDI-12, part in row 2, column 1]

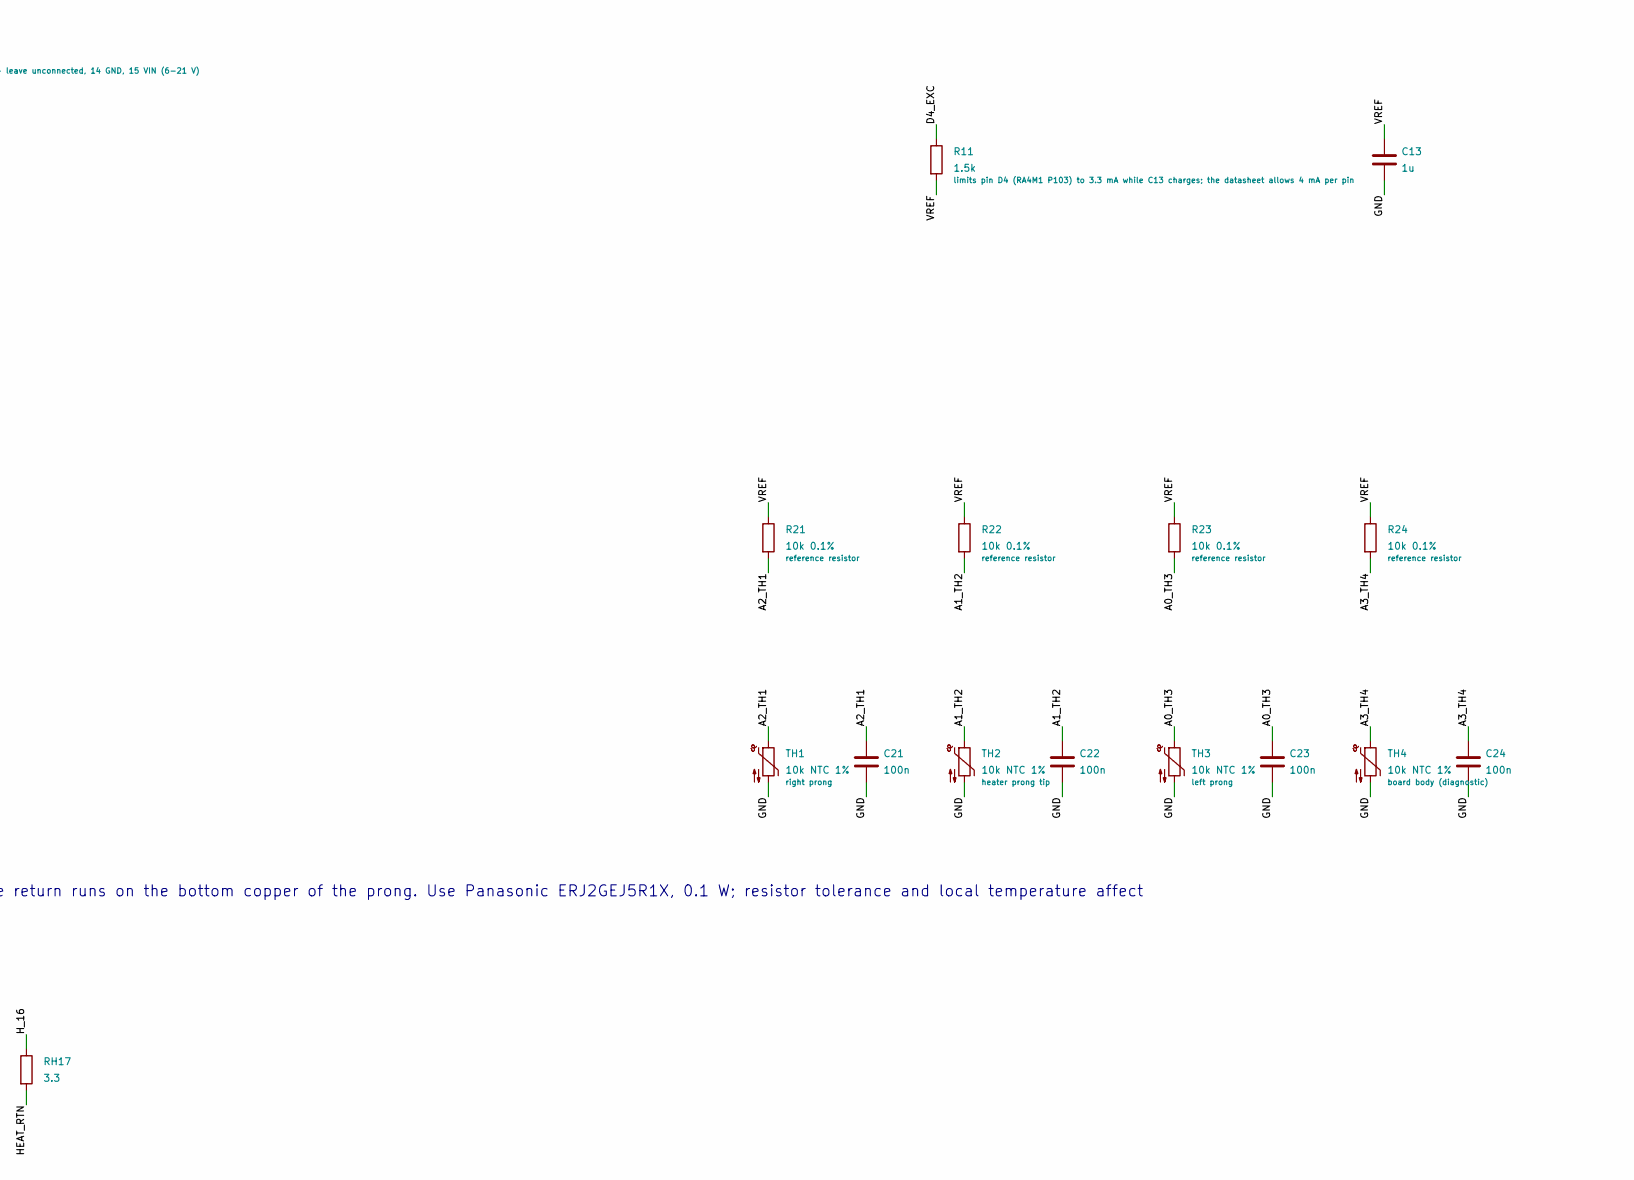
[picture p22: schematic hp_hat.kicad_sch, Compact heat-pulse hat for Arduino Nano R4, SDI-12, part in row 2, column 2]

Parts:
C1, C17: 10u 50V; C_0805_2012Metric
C3: 22u 25V; C_1206_3216Metric
C4: 3.3n; C_0402_1005Metric
C12, C21, C22, C23, C24: 100n; C_0402_1005Metric
C13: 1u; C_0402_1005Metric
D1: 1A 40V Schottky (SOD-323); D_SOD-323
D2: SMF15CA 15V bidir TVS; D_SOD-123F
D4: bidir ESD diode 6-7V (SOD-323); D_SOD-323
J1: Hand-soldered cable (3 wires); CableSolder_1x03
J3, J4: Nano solder-stack header; Nano_SolderStack_1x15
Q1: AO3400A; SOT-23
R3: 1.5k 1%; R_0603_1608Metric
R4: 220k; R_0402_1005Metric
R5: 0.1 1%; R_0805_2012Metric
R6, R7: 4.7k; R_0402_1005Metric
R9, R11: 1.5k; R_0402_1005Metric
R10: 100k; R_0402_1005Metric
R18: 22; R_0603_1608Metric
R21, R22, R23, R24: 10k 0.1%; R_0603_1608Metric
RH1, RH2, RH3, RH4, RH5, RH6, RH7, RH8, RH9, RH10, RH11, RH12, RH13, RH14, RH15, RH16, RH17: 3.3; R_0603_Vishay_HP
TH1, TH2, TH3, TH4: 10k NTC 1%; R_0402_1005Metric
U4: INA226; MSOP-10_3x3mm_P0.5mm

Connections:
+5V: C12.1, C17.1, J4.12, R6.1, R7.1, U4.6 (VS)
A0_TH3: C23.1, J4.4, R23.2, TH3.1
A1_TH2: C22.1, J4.5, R22.2, TH2.1
A2_TH1: C21.1, J4.6, R21.2, TH1.1
A3_TH4: C24.1, J4.7, R24.2, TH4.1
A4_SDA: J4.8, R6.2, U4.4 (SDA)
A5_SCL: J4.9, R7.2, U4.5 (SCL)
D2_SDI12: J3.11, R3.2
D4_EXC: J3.9, R11.1
D9_HEAT: J3.4, R9.1
GND: C1.2, C3.2, C4.2, C12.2, C13.2, C17.2, C21.2, C22.2, C23.2, C24.2, D2.2 (A2), D4.2 (A2), J1.3, J3.12, J4.14, Q1.2 (S), R4.2, R10.2, TH1.2, TH2.2, TH3.2, TH4.2, U4.1 (A1), U4.2 (A0), U4.7 (GND)
HEAT_GATE: Q1.1 (G), R9.2, R10.1
HEAT_P: R5.2, RH1.1, U4.8 (Vbus), U4.9 (Vin-)
HEAT_RTN: Q1.3 (D), RH17.2
H_1: RH1.2, RH2.1
H_2: RH2.2, RH3.1
H_3: RH3.2, RH4.1
H_4: RH4.2, RH5.1
H_5: RH5.2, RH6.1
H_6: RH6.2, RH7.1
H_7: RH7.2, RH8.1
H_8: RH8.2, RH9.1
H_9: RH9.2, RH10.1
H_10: RH10.2, RH11.1
H_11: RH11.2, RH12.1
H_12: RH12.2, RH13.1
H_13: RH13.2, RH14.1
H_14: RH14.2, RH15.1
H_15: RH15.2, RH16.1
H_16: RH16.2, RH17.1
NANO_VIN: J4.15, R18.2
SDI_LINE: C4.1, D4.1 (A1), J1.2, R3.1, R4.1
VIN: D1.2 (A), D2.1 (A1), J1.1
VIN_P: C1.1, C3.1, D1.1 (K), R5.1, R18.1, U4.10 (Vin+)
VREF: C13.1, J4.3, R11.2, R21.1, R22.1, R23.1, R24.1

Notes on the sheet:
POWER IN - 12 V battery / logger supply, normally 11.5-14.4 V, through three soldered wires. D1 provides reverse-polarity protection. The Nano VIN branch uses R18; its onboard regulator supplies the hat's 5 V. The TVS and R18 do not guarantee a 21 V surge limit.
SDI-12 DATA - R3 limits transmit and fault current; R4 sets the idle load. C4 slows transitions and D4 provides ESD protection. Direct 5 V GPIO receive thresholds are not guaranteed for every compliant SDI-12 sender; verify with the intended logger and cable.
ARDUINO NANO R4 ABX00142 - two Samtec HTSW-115-07-T-S 1x15 strips soldered through BOTH boards; components face inward. Seat header insulators on hat front and use a fixture to hold a 4.00 mm board gap during soldering. Trim solid pin tails to 0.5 mm maximum outside each board. USB-C faces the cabl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
HEATER DRIVE + POWER MONITOR - heater runs from the battery, never from USB alone. Firmware must bound pulse duration to 15 s, monitor V and I, and switch OFF on timeout or a fault. Refuse heating above 15 V input. R10 holds the gate low when D9 is high impedance; it is not a watchdog.
HEATER RESISTOR CHAIN (top side of the center prong only) - 17 x 3.3 ohm 1% 0603 in series, 2.6 mm pitch. EXACT Vishay CRCW06033R30FKEAHP, 0.33 W at 70 C. The return runs on the bottom copper of the prong. Use Panasonic ERJ2GEJ5R1X, 0.1 W; resistor tolerance and local temperature affect the margin.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
THERMISTORS - pin map (same as flat-nano): A2 = TH1 right needle, A1 = TH2 heater-needle tip, A0 = TH3 left needle, A3 = TH4 board body (left/right seen on the top face, toward the Nano, cable end up, needles down; from the outer face they appear swapped). Dividers and Nano AREF share VREF. D4 powe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

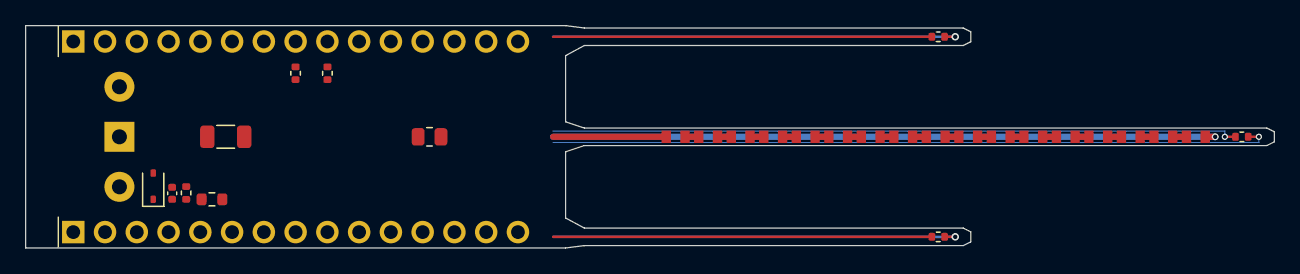
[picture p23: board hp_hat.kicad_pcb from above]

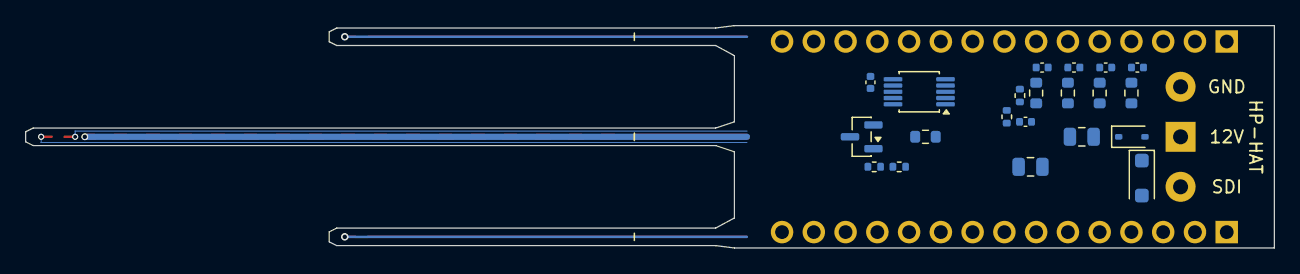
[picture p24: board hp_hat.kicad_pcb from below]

Board: 4 copper layers, 99.9 x 17.8 mm, 52 parts (21 on the bottom side), 35 nets.

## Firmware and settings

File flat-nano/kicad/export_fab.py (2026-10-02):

"""Generate the compact HP-SDI12-NANO package from one checked four-layer board.
All CAM, assembly data and previews are staged under flat-nano/checks/tmp on D:.
Only after generation and validation succeed is the package published to flat-nano/fab (overwritten in place).
Use release.py for a checked release and manifest; this exporter alone is not a release.
"""
import csv, hashlib, json, os, shutil, subprocess, sys, tempfile, zipfile
from pathlib import Path

HERE = Path(__file__).resolve().parent
VARIANT = HERE.parent
if VARIANT.name != "flat-nano":
    raise SystemExit("This exporter is restricted to the flat-nano project")
os.chdir(HERE)
TMP = VARIANT / "checks" / "tmp"
TMP.mkdir(parents=True, exist_ok=True)
os.environ["TEMP"] = os.environ["TMP"] = str(TMP)
tempfile.tempdir = str(TMP)
sys.dont_write_bytecode = True
sys.path.insert(0, str(VARIANT / "checks"))
from fabrication_helpers import board_stackup, stackup_issues, normalize_job, job_stackup_issues, schematic_footprint_matches

PREFIX = "HP-SDI12-NANO"
EXCLUDED = {"J1", "J2"}  # Bare cable and programming pads; no factory-fitted connectors.
JLC_ROT = {"LQFP-64": 270, "MSOP-10": 270, "SOT-89": 180, "SOT-23": 180}
CLI = str(Path(sys.executable).with_name("kicad-cli.exe"))
PCB = HERE / "hp_sensor_routed.kicad_pcb"
SCH = HERE / "hp_sensor.kicad_sch"
FAB = VARIANT / "fab"
CAM_LAYERS = "F.Cu,In1.Cu,In2.Cu,B.Cu,F.Paste,F.SilkS,B.SilkS,F.Mask,B.Mask,Edge.Cuts"
CAM_SUFFIXES = {"-F_Cu.gtl", "-In1_Cu.g1", "-In2_Cu.g2", "-B_Cu.gbl", "-F_Paste.gtp",
                "-F_Silkscreen.gto", "-B_Silkscreen.gbo", "-F_Mask.gts", "-B_Mask.gbs",
                "-Edge_Cuts.gm1", "-PTH.drl", "-NPTH.drl", "-job.gbrjob"}
EXPECTED_CAM = {PCB.stem + suffix for suffix in CAM_SUFFIXES}
EXPECTED_OUTPUTS = {PREFIX + suffix for suffix in ("_gerbers.zip", "_BOM.csv", "_CPL.csv", "_schematic.pdf")} | {"render_top.png", "render_bottom.png"}


def staged_cam_files(directory):
    files = list(Path(directory).iterdir())
    if any(not p.is_file() or p.is_symlink() for p in files):
        raise ValueError("CAM staging must contain regular files only")
    actual = {p.name for p in files}
    if actual != EXPECTED_CAM:
        raise ValueError(f"Invalid CAM set; missing={sorted(EXPECTED_CAM - actual)}, stale={sorted(actual - EXPECTED_CAM)}")
    if any(p.stat().st_size == 0 for p in files):
        raise ValueError("Empty CAM file")
    return sorted(files, key=lambda p: p.name)


def self_test():
    with tempfile.TemporaryDirectory(prefix="flat-nano-cam-test-", dir=TMP) as directory:
        root = Path(directory)
        for name in EXPECTED_CAM: (root / name).write_text("fixture", encoding="utf8")
        assert len(staged_cam_files(root)) == 13
        for name, make, remove in (
            ("stale file", lambda: (root / "old.gbr").write_text("stale"), lambda: (root / "old.gbr").unlink()),
            ("missing layer", lambda: (root / (PCB.stem + "-In2_Cu.g2")).unlink(), lambda: (root / (PCB.stem + "-In2_Cu.g2")).write_text("fixture")),
            ("unexpected directory", lambda: (root / "extra").mkdir(), lambda: (root / "extra").rmdir()),
        ):
            make()
            try: staged_cam_files(root)
            except ValueError: pass
            else: raise AssertionError(f"Accepted {name}")
            remove()
    print("PASS: four fresh-CAM staging regression fixtures")


def run(*args):
    result = subprocess.run([CLI, *map(str, args)], capture_output=True, text=True)
    if result.returncode:
        raise RuntimeError("kicad-cli failed: " + " ".join(map(str, args)) + "\n" + result.stdout + result.stderr)


def build_cam(stage):
    stack = board_stackup(PCB.read_text(encoding="utf8"))
    issues = stackup_issues(stack)
    if issues: raise ValueError("Invalid fabrication setup: " + "; ".join(issues))
    gerbers = stage / "gerbers"
    gerbers.mkdir()
    run("pcb", "export", "gerbers", "-o", str(gerbers) + os.sep, "--layers", CAM_LAYERS, "--subtract-soldermask", PCB)
    run("pcb", "export", "drill", "-o", str(gerbers) + os.sep, "--format", "excellon", "--excellon-units", "mm", "--excellon-separate-th", PCB)
    jobpath = gerbers / (PCB.stem + "-job.gbrjob")
    job = normalize_job(json.loads(jobpath.read_text(encoding="utf8")), stack)
    issues = job_stackup_issues(job, stack)
    if issues: raise ValueError("Invalid Gerber-job metadata: " + "; ".join(issues))
    jobpath.write_text(json.dumps(job, indent=2) + "\n", encoding="utf8")
    files = staged_cam_files(gerbers)
    with zipfile.ZipFile(stage / (PREFIX + "_gerbers.zip"), "w", zipfile.ZIP_DEFLATED) as archive:
        for source in files: archive.write(source, source.name)


MPN = {  # value -> (description, manufacturer part number, JLCPCB/LCSC number if verified by the Sept-2026 audit, else "")
    "3.3": ("HEATER: Vishay high-power 0603 3.3 ohm 1%, 0.33 W at 70 C, derates above 70 C. Exact CRCW-HP part required; no ordinary 0.1 W/0.125 W substitutes", "CRCW06033R30FKEAHP", "C313752"),
    "1.5k": ("Resistor 1.5 k ohm 1%, 0402 (R9 gate drive, R11 thermistor excitation)", "0402WGF1501TCE", "C25867"),
    "R7FA4M1AB3CFM": ("Renesas RA4M1 MCU, LQFP-64", "R7FA4M1AB3CFM#AA0", "C1340737"),
    "INA226": ("TI INA226 power monitor, VSSOP-10", "INA226AIDGSR", "C49851"),
    "LMR36503R5RPER": ("TI 5 V synchronous buck, 3-65 V in, 300 mA, VQFN-HR-9 2x2 mm", "LMR36503R5RPER", "C3190197"),
    "22uH": ("Power inductor 22 uH 20 %, 0.62 A saturation, 4x4 mm (buck)", "SWPA4020S220MT", "C82401"),
    "AO3400A": ("N-MOSFET 30 V logic level, SOT-23", "AO3400A", "C20917"),
    "WAGO 2060-453 push-in": ("WAGO SMD push-in terminal, 3-pole, 4 mm", "2060-453/998-404", "C2765056"),
    "1A 40V Schottky (SOD-323)": ("Schottky 1 A 40 V, SOD-323", "1N5819WS", "C191023"),
    "SMF16CA 16V bidir TVS": ("TVS 16 V standoff, bidirectional, SOD-123FL (clamp about 26 V)", "SMF16CA", "C19077511"),
    "SMF15CA 15V bidir TVS": ("TVS 15 V standoff, bidirectional, SOD-123FL (clamp about 24 V)", "SMF15CA", "C19077510"),
    "bidir ESD diode 6-7V (SOD-323)": ("ESD diode bidirectional 5 V, SOD-323", "PESD5V0S1BA,115", "C19224"),
    "10k NTC 1%": ("NTC thermistor 10 k 1 % B3380, 0402 - no substitutes", "NCP15XH103F03RC", "C77131"),
    "10k 0.1%": ("Resistor 10 k 0.1 % 25 ppm, 0603 - no substitutes", "CRF0603Q103BN", "C54973934"),
    "0.1 1%": ("Current-sense resistor 0.1 ohm 1 %, 0805 - no substitutes", "WSL0805R1000FEA", "C2094615"),
    "5.1": ("HEATER resistor 5.1 ohm 5 % 0402, Panasonic ERJ-2GE, 0.1 W (0.055 W each at 12 V, 0.099 W at 16 V). Must be a 0.1 W part - do NOT accept an ordinary 1/16 W (62.5 mW) 0402", "ERJ2GEJ5R1X", "C412902"),
    "10u 50V": ("MLCC 10 uF 50 V X5R 0805 (VIN input C1 and +5 V output C17)", "GRM21BR61H106KE43L", "C440198"),
    "4.7u": ("MLCC 4.7 uF 16 V X5R 0603", "CL10A475KO8NNNC", "C19666"),
    "1.5k 1%": ("Resistor 1.5 k 1 % 0603 (SDI-12 transmit resistance)", "0603WAF1501T5E", "C22843"),
    # plain 0402 parts: exact JLCPCB numbers are REQUIRED - left blank, JLCPCB's matcher reads "0402_1005Metric" as the far smaller 01005 size
    "22u 25V": ("MLCC 22 uF 25 V X5R 1206 (bulk input capacitor C3 and buck output capacitor C2)", "CL31A226KAHNNNE", "C12891"),
    "100n": ("MLCC 100 nF 50 V X7R 0402", "CL05B104KB54PNC", "C307331"),
    "1u": ("MLCC 1 uF 25 V X5R 0402", "CL05A105KA5NQNC", "C52923"),
    "3.3n": ("MLCC 3.3 nF 50 V X7R 0402", "CL05B332KB5NNNC", "C26404"),
    "22": ("Resistor 22 ohm 1 % 0603", "0603WAF220JT5E", "C23345"),
    "10": ("Resistor 10 ohm 1 % 0402", "0402WGF100JTCE", "C25077"),
    "1k": ("Resistor 1 k 1 % 0402", "0402WGF1001TCE", "C11702"),
    "4.7k": ("Resistor 4.7 k 1 % 0402", "0402WGF4701TCE", "C25900"),
    "5.1k": ("Resistor 5.1 k 1 % 0402", "0402WGF5101TCE", "C25905"),
    "10k": ("Resistor 10 k 1 % 0402", "0402WGF1002TCE", "C25744"),
    "100k": ("Resistor 100 k 1 % 0402", "0402WGF1003TCE", "C25741"),
    "220k": ("Resistor 220 k 1 % 0402", "0402WGF2203TCE", "C25767"),
    "socket row D12..TX (pin 1 at the USB end)": ("Female header socket 1x15, 2.54 mm, through-hole, 8.5 mm tall", "HX PM2.54-1x15P ZC", "C41417327"),
    "socket row D13..VIN (pin 1 at the USB end)": ("Female header socket 1x15, 2.54 mm, through-hole, 8.5 mm tall", "HX PM2.54-1x15P ZC", "C41417327"),
}
def build_assembly(stage):
    import pcbnew
    board = pcbnew.LoadBoard(str(PCB))
    if board.GetCopperLayerCount() != 4:
        raise ValueError("The compact flat-nano requires four copper layers")
    parts = json.loads((HERE / "netlist.json").read_text(encoding="utf8"))["parts"]
    expected = set(parts) - EXCLUDED
    actual = {fp.GetReference(): fp for fp in board.GetFootprints()}
    if set(parts) != set(actual): raise ValueError("Board and assembly source reference sets differ")
    for ref, part in parts.items():
        fp = actual[ref]
        if fp.GetValue() != part["value"] or not schematic_footprint_matches(part["footprint"], fp.GetFPIDAsString()):
            raise ValueError(f"Board/source value or footprint differs at {ref}")
    pos = stage / "_pos.csv"
    run("pcb", "export", "pos", "--format", "csv", "--units", "mm", "--side", "front", "--exclude-dnp", "-o", pos, PCB)
    with pos.open(encoding="utf8") as stream:
        rows = [r for r in csv.DictReader(stream) if r["Ref"] not in EXCLUDED]
    pos.unlink()
    if len(rows) != len(expected) or {r["Ref"] for r in rows} != expected:
        raise ValueError("Front-side placement list must include every fitted flat-nano component exactly once")
    with (stage / (PREFIX + "_CPL.csv")).open("w", newline="", encoding="utf8") as stream:
        writer = csv.writer(stream)
        writer.writerow(["Designator", "Mid X", "Mid Y", "Layer", "Rotation"])
        for row in rows:
            offset = next((v for k, v in JLC_ROT.items() if k in row["Package"]), 0)
            writer.writerow([row["Ref"], f'{float(row["PosX"]):.4f}mm', f'{float(row["PosY"]):.4f}mm', "Top", f'{(float(row["Rot"]) + offset) % 360:.0f}'])
    groups = {}
    for ref in sorted(expected):
        part = parts[ref]
        value, footprint = part["value"], part["footprint"].split(":", 1)[1]
        if value not in MPN or not all(MPN[value]):
            raise ValueError(f"Exact assembly part mapping missing for {ref}: {value}")
        description, mpn, lcsc = MPN[value]
        if lcsc in groups:
            if groups[lcsc][2] != footprint: raise ValueError(f"Inconsistent footprint for {lcsc}")
            groups[lcsc][1].append(ref)
        else: groups[lcsc] = [value, [ref], footprint, lcsc, mpn, description]
    key = lambda r: (r.rstrip("0123456789"), int("".join(c for c in r if c.isdigit()) or 0))
    with (stage / (PREFIX + "_BOM.csv")).open("w", newline="", encoding="utf8") as stream:
        writer = csv.writer(stream)
        writer.writerow(["Comment", "Designator", "Footprint", "LCSC Part #", "Manufacturer Part Number", "Qty", "Description"])
        for value, refs, footprint, lcsc, mpn, description in sorted(groups.values(), key=lambda r: key(min(r[1], key=key))):
            writer.writerow([value, ",".join(sorted(refs, key=key)), footprint, lcsc, mpn, len(refs), description])
    return len(expected), len(groups)


def publish(stage):
    # Validate resolved absolute paths before replacing/removing generated files.
    destination = FAB.resolve()
    if destination != VARIANT.resolve() / "fab" or FAB.is_symlink():
        raise ValueError("Unexpected manufacturing output path")
    destination.mkdir(parents=True, exist_ok=True)
    allowed = EXPECTED_OUTPUTS | {"gerbers", "RELEASE_MANIFEST.txt", "ORDER_SETTINGS.md", "README.md"}
    unexpected = {path.name for path in destination.iterdir()} - allowed
    if unexpected:
        raise ValueError(f"Unexpected pre-existing files in the output; refusing a mixed package: {sorted(unexpected)}")
    gerbers = destination / "gerbers"
    if gerbers.is_symlink() or gerbers.resolve() != destination / "gerbers":
        raise ValueError("Redirected loose-CAM directory")
    gerbers.mkdir(exist_ok=True)
    old_cam = list(gerbers.iterdir())
    for old in old_cam:
        if old.is_symlink() or not old.is_file() or old.resolve().parent != gerbers:
            raise ValueError("Unexpected non-file/redirect in loose-CAM directory")
    for name in EXPECTED_OUTPUTS | {"RELEASE_MANIFEST.txt"}:
        path = destination / name
        if path.is_symlink() or (path.exists() and not path.is_file()) or path.resolve().parent != destination:
            raise ValueError(f"Unexpected fabrication output target: {name}")
    (destination / "RELEASE_MANIFEST.txt").write_text(
        "NOT RELEASED: HP-SDI12-NANO package generation is complete; release.py must finish independent checks.\n", encoding="utf8")
    for source in staged_cam_files(stage / "gerbers"):
        temporary = gerbers / (source.name + ".tmp")
        if temporary.exists(): raise ValueError(f"Unexpected temporary output: {temporary}")
        shutil.copyfile(source, temporary)
        os.replace(temporary, gerbers / source.name)
    for old in old_cam:
        if old.name not in EXPECTED_CAM: old.unlink()
    for name in sorted(EXPECTED_OUTPUTS):
        temporary = destination / (name + ".tmp")
        if temporary.exists(): raise ValueError(f"Unexpected temporary output: {temporary}")
        shutil.copyfile(stage / name, temporary)
        os.replace(temporary, destination / name)


def build_package(stage):
    """Write a complete fresh package, without changing the published release."""
    stage = Path(stage).resolve()
    if TMP.resolve() not in stage.parents or not stage.is_dir() or any(stage.iterdir()):
        raise ValueError("Package staging must be an empty directory under flat-nano/checks/tmp")
    build_cam(stage)
    count, groups = build_assembly(stage)
    for side in ("top", "bottom"):
        run("pcb", "render", "--side", side, "-w", "2600", "-h", "760", "--zoom", "3", "--background", "opaque", "-o", stage / f"render_{side}.png", PCB)
    run("sch", "export", "pdf", "-o", stage / (PREFIX + "_schematic.pdf"), SCH)
    files = {p.name for p in stage.iterdir() if p.is_file()}
    if files != EXPECTED_OUTPUTS or any((stage / name).stat().st_size == 0 for name in files):
        raise ValueError("Incomplete/extra manufacturing package output")
    return count, groups


def main():
    if sys.argv[1:] == ["--self-test"]:
        self_test()
        return
    if sys.argv[1:]: raise SystemExit("Use export_fab.py or export_fab.py --self-test; BOM-only edits are not release-safe")
    frozen = {path: hashlib.sha256(path.read_bytes()).hexdigest()
              for path in (PCB, SCH, HERE / "netlist.json", Path(__file__).resolve())}
    with tempfile.TemporaryDirectory(prefix="flat-nano-fab-stage-", dir=TMP) as directory:
        stage = Path(directory)
        count, groups = build_package(stage)
        if any(hashlib.sha256(path.read_bytes()).hexdigest() != digest for path, digest in frozen.items()):
            raise ValueError("Manufacturing source changed while the package was generated or checked")
        publish(stage)
    print(f"Generated {PREFIX}: {count} fitted parts, {groups} BOM lines; four copper layers")
    print(f"Package: {FAB}")
    print("J1/J2 bare pads excluded from factory assembly; run release.py to certify the checked package")


if __name__ == "__main__":
    main()

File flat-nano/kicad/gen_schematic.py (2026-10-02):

"""Compact flat heat-pulse sensor, HP-SDI12-NANO - schematic generator.
Higher-power heater with PWM control capability; J1 is three hand-soldered cable holes.

Run:  D:\KiCAD\bin\python.exe gen_schematic.py
Writes hp_sensor.kicad_sch (+ netlist.json used later by the PCB generator).
The circuit is DATA (the PARTS list below): edit a value / net there and re-run; do not hand-edit the .kicad_sch.
Every pin gets a short stub and a net label, grouped by functional block - no long wires to trace.
"""
import json, uuid, os
from sexpr import Sym, dump, get_symbol, pins, find

os.chdir(os.path.dirname(os.path.abspath(__file__)))

PROJECT = "hp_sensor"
N_HEAT = 17            # One-sided 0603 chain: 43.2 mm body-to-body heated extent.
PITCH = 2.6
R_HEAT = "3.3"         # 56.1 ohm total; Vishay CRCW06033R30FKEAHP, 0.33 W at 70 C.
ROOT = str(uuid.uuid4())
uid = lambda: str(uuid.uuid4())

FP = dict(R0402="Resistor_SMD:R_0402_1005Metric", R0603="Resistor_SMD:R_0603_1608Metric", R0805="Resistor_SMD:R_0805_2012Metric",
          C0402="Capacitor_SMD:C_0402_1005Metric", C0603="Capacitor_SMD:C_0603_1608Metric", C0805="Capacitor_SMD:C_0805_2012Metric")
PARTS, TEXTS = [], []


def part(ref, lib, value, fp, x, y, pinmap, **fields):
    x, y = round(x / 2.54) * 2.54, round(y / 2.54) * 2.54          # snap to the 100 mil schematic grid
    PARTS.append(dict(ref=ref, lib=lib, value=value, fp=fp, x=x, y=y, pins={str(k): v for k, v in pinmap.items()}, fields=fields))


def two(ref, lib, value, fp, x, y, a, b, **f):          # vertical 2-pin part: pin 1 on top
    part(ref, lib, value, fp, x, y, {1: a, 2: b}, **f)


def text(s, x, y, size=2.0, right=585):
    import textwrap                                         # wrap so headings never run off the sheet (KiCad text anchors at the bottom line)
    width = int((right - x) / (size * 0.95))
    lines = [w for para in s.splitlines() for w in (textwrap.wrap(para, width) or [""])]
    TEXTS.append((chr(10).join(lines), x, y + (len(lines) - 1) * size * 1.7, size))


def flag(n, net, x, y):
    part(f"#FLG{n:02d}", "power:PWR_FLAG", "PWR_FLAG", "", x, y, {1: net})


# ------------------------------------------------------------------ POWER ------------------------------------------------------------------
X, Y = 40, 60
text("HP-SDI12-NANO / COMPACT FLAT   -   11.5-14.4 V battery supply over the 3-wire SDI-12 cable. J1 has three bare cable solder holes (VIN, data, ground); no connector is fitted. "
     "5 V comes from a buck converter (TI LMR36503R5, 5 V fixed, ~4 uA no-load, 2.2 MHz with RT tied to GND), which wastes several times less heat than a linear regulator.", 30, 25, 2.0, right=300)
part("J1", "Connector_Generic:Conn_01x03", "Hand-soldered cable (3 wires)", "hp_sensor:CableSolder_1x03", X, Y, {1: "VIN", 2: "SDI_LINE", 3: "GND"},
     Note="1 = 12V (center hole, square), 2 = SDI-12 data, 3 = GND; hand-solder after assembly, add cable strain relief")
two("D2", "Device:D_TVS", "SMF16CA 16V bidir TVS", "Diode_SMD:D_SOD-123F", X + 40, Y, "VIN", "GND")
two("D1", "Device:D_Schottky", "1A 40V Schottky (SOD-323)", "Diode_SMD:D_SOD-323", X + 75, Y, "VIN_P", "VIN", Note="reverse-polarity protection")
two("C1", "Device:C", "10u 50V", FP["C0805"], X + 100, Y, "VIN_P", "GND", Note="buck input capacitor (datasheet minimum 4.7 uF)")
two("C3", "Device:C", "22u 25V", "Capacitor_SMD:C_1206_3216Metric", X + 100, Y + 20, "VIN_P", "GND", Note="bulk: supplies the heater switching edges locally")
two("C18", "Device:C", "100n", FP["C0402"], X + 115, Y + 20, "VIN_P", "GND", Note="high-frequency input bypass at U3 VIN/GND")
part("U3", "hp_sensor:LMR36503R5", "LMR36503R5RPER", "hp_sensor:TI_RPE0009A_VQFN-HR-9_2x2mm", X + 135, Y + 5,
     {1: "GND", 2: None, 3: "VIN_P", 4: "VIN_P", 5: "SW", 6: "BOOT", 7: "VCC_BUCK", 8: "5V_BUCK", 9: "GND"},
     Note="5 V fixed buck; RT to GND = 2.2 MHz; EN tied to VIN; PGOOD unused")
two("C19", "Device:C", "100n", FP["C0402"], X + 165, Y - 10, "BOOT", "SW", Note="bootstrap capacitor")
two("C20", "Device:C", "1u", FP["C0402"], X + 165, Y + 20, "VCC_BUCK", "GND", Note="internal LDO capacitor")
two("L1", "Device:L", "22uH", "Inductor_SMD:L_Sunlord_SWPA4020S", X + 180, Y - 10, "SW", "5V_BUCK", Note="Sunlord SWPA4020S220MT, 0.62 A saturation")
two("C2", "Device:C", "22u 25V", "Capacitor_SMD:C_1206_3216Metric", X + 180, Y + 20, "5V_BUCK", "GND", Note="buck output capacitor (22 uF rated)")
two("D7", "Device:D_Schottky", "1A 40V Schottky (SOD-323)", "Diode_SMD:D_SOD-323", X + 228, Y, "+5V", "5V_BUCK", Note="keeps USB power out of the regulator (as on the Nano R4)")
two("C17", "Device:C", "10u 50V", FP["C0805"], X + 252, Y, "+5V", "GND")
two("D5", "Device:D_Schottky", "1A 40V Schottky (SOD-323)", "Diode_SMD:D_SOD-323", X + 195, Y, "+5V", "VUSB", Note="bench power from the USB pads")
for i, net in enumerate(["VIN", "VIN_P", "GND", "VUSB", "+5V"]):
    flag(i + 1, net, X + 40 + 25 * i, Y + 35)

# ------------------------------------------------------------------ SDI-12 ------------------------------------------------------------------
X, Y = 300, 60
text("SDI-12 DATA   -   meets the SDI-12 electrical numbers: R3 sets the 1-2 k transmit resistance (and limits fault current into pin D2), R4 the 160-360 k idle resistance, "
     "C4 holds the edge rate under 1.5 V/us. D4 clamps cable transients.", 285, 22, 2.0, right=425)
two("R3", "Device:R", "1.5k 1%", FP["R0603"], X, Y, "SDI_LINE", "D2_SDI12")
two("R4", "Device:R", "220k", FP["R0402"], X + 60, Y, "SDI_LINE", "GND")
two("C4", "Device:C", "3.3n", FP["C0402"], X + 75, Y, "SDI_LINE", "GND")
two("D4", "Device:D_TVS", "bidir ESD diode 6-7V (SOD-323)", "Diode_SMD:D_SOD-323", X + 30, Y, "SDI_LINE", "GND")
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

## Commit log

2026-09-25 New repo with heat pulse twin
    [ABX00142.step, HP-HAT_BOM.csv, HP-SDI12-NANO_BOM.csv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]
2026-09-29 Update flat-nano and hat to the reviewed designs; refresh the website
    Boards (both at the Arduino Nano R4 outline, 43.18 x 17.78 mm):
    - Hand-routed copper (preroute.py) replaces the auto-router; release.py
    rebuilds, checks (ERC, DRC all severities, parity, Kelvin, solder vias,
    layout quality) and exports the order files with a release manifest.
    - Layout quality gate: power copper >= 0.5 mm outer / 1.2 mm inner,
    heat sources on the center line, mirrored side needles, left/right
    copper within 10% on every layer.
    - flat-nano: 5 V buck regulator (LMR36503), single-sided assembly,
    cable solder holes, programming-clip holes. Hat: parts on both faces,
    Nano pins kept.
    - R11 330 ohm -> 1.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
    [HP-HAT_BOM.csv, HP-SDI12-NANO_BOM.csv, hp_hat.kicad_pcb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]
2026-09-29 Twin: colormap to the sensor head, references dialog, visible thermistor readings
    - The soil colormap now starts at the sensor head (end of the PCB body)
    instead of 8 mm past it.
    - New References dialog (footer and About dialog): line-source and
    dual-probe heat-pulse theory, error analysis, de Vries, and the Kansas
    Mesonet soil data, with DOIs checked against Crossref.
    - Thermistor copper stays dim pink while the sensor samples and flashes
    at each reading for 15% of the played-back sample interval (at least
    one redraw), so the 20 ms reading pulse is visible at 4x and 10x.
    Paused or scrubbed, it lights exactly while pin D4 is HIGH.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
2026-09-29 Twin: effective heater length, fit to just past the peak, 150 s cooling
    - Sensor estimate divides heater power by the effective line length,
    17 resistors x 2.6 mm = 44.2 mm (was 43.2 mm, resistor end to end,
    which overstated q' by 2.3%).
    - The line-source fit runs from heater-on to 1.5 x the measured peak
    time. The peak's size and timing carry the information; the tail is
    where the ideal line agrees least with the finite heater, and fitting
    it pulled lambda and alpha up. Later readings are kept, not fitted.
    The estimate is flagged when the record ends before the peak.
    - Default cooling phase 150 s (was 90 s): the latest Kansas peak comes
    98 s after heater-on (oven-dry core), so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
2026-09-30 Add the primer page: how the sensor works, linked from the twin footer
    docs/primer/index.html is the introductory chapter on the electronics and
    the heat-transfer model, with its figures in docs/primer/fig/. Contents
    entries link to each section; on screens the page is centered at a
    readable width and fits phones.
2026-10-02 Prefer JLC Basic/Preferred parts and fewer BOM lines; wider primer page
    Flat-nano 27 -> 25 BOM lines (13 -> 9 Extended), hat 21 -> 20 (10 -> 6):
    - Schottky diodes: 1N5819WS C191023 (Basic, same SOD-323)
    - C1 and C17: one 10 uF 50 V 0805 part, C440198 (Basic)
    - all 100 nF: the 50 V part C307331 (Basic)
    - C4 3.3 nF: C26404 (Preferred); SMF16CA/SMF15CA TVS: C19077511/C19077510 (Preferred)
    Copper and placement unchanged (all tracks, vias and positions identical); full
    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
    [HP-HAT_BOM.csv, HP-SDI12-NANO_BOM.csv, hp_hat.kicad_pcb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]
